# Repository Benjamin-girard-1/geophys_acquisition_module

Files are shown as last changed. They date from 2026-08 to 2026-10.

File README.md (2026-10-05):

# Geophysical Acquisition Module

Hardware, embedded firmware, protocol, and host-side software for a modular
geophysical data-acquisition system.

Version 2 uses an ESP32-S3 DevKit as its immutable compute platform and a custom
carrier PCB organized by hardware revision. The current hardware design includes
an AD7779 ADC, an LSM6DSV IMU, MAX-M10S GNSS, SD storage shared with a USB2641,
74HC/HCT595 GPIO expansion, and removable analog acquisition cards.

## Current status

The Version 2 firmware builds with ESP-IDF 5.5. Board safe-state and power
control, portable GPIO/SPI/UART, calibrated analog-input, and ROM-backed CRC
mechanisms, the 74HC/HCT595 driver, bounded analog-card ID measurement, and the
AD7779 register, lifecycle, channel/gain, fixed output-rate, signed sample
decoding, and conversion-frame validation foundations are implemented.
The acquisition task, SD recording owner, and recording controller now provide
the first end-to-end recording implementation and UART live-stream path, while
the remaining protocol inventory is still in progress. Hardware verification
is being completed incrementally.
The authoritative protocol defines fixed 64-byte command messages and portable
512-byte ADC data blocks shared by live capture and SD recording. Fixed command
framing, incremental stream recovery, CRC validation, and the
`HELLO`/`DEVICE_INFO` plus `DEVICE_GET_CONFIG`/`DEVICE_SET_CONFIG` UART slices
are implemented and verified on Rev-1 hardware. Live start/stop, complete
512-byte UART data delivery, the five SD-recording commands,
the portable `\DAT` encoder/decoder, fixed recording-buffer pool, and FatFs
writer are implemented; a clean Rev-1 build mounts and catalogs the SD card,
and now creates, syncs, closes, catalogs, and deletes ADC data files on Rev-1
hardware. A temporary test-only `0xf000` command can read closed recording
files in 38-byte UART chunks; it is implemented in the firmware and host codec
and was used to retrieve and CRC-validate a stored 512-byte block. A two-second
protocol probe produced and cleanly closed 404 fixed
512-byte records while configuration commands remained responsive. The probe
also exposed and led to correction of acquisition-task starvation and a
FreeRTOS queue-set accounting error that rebooted the device after several SD
records. Comparison with the working V1 driver identified and corrected
premature post-reset polling failure, missing reference-output power, missing
SPI software reset, and missing filter synchronization. The earlier all-zero
ADC response was a bench power issue: the main +5 V supply was absent, so 3V3A
was unavailable. Restoring +5 V allowed AD7779 initialization and recording to
proceed. The two expendable recordings that filled the card were enumerated
and deleted through the recording protocol, leaving an empty catalog. A
subsequent fresh probe recorded, downloaded, validated, and deleted ten
512-byte records. All record framing and CRCs passed. That early capture
contained 80 startup conversions near the AD7779 reset rate followed by a
sequence gap. The cause was an ESP-IDF side effect that enabled the DRDY pin
while its handler was attached, before ADC synchronization and SRC settling
completed. The platform attach operation now restores the pin to disabled and
the application enables it explicitly after `ad7779_start()`. A fresh 1 kSPS
probe then produced 25 status-OK records with no missing conversions. The
acquisition hot path now reserves SPI2 and its DMA resources once and launches
one hardware-CS-framed, prepared 32-byte transfer for each DRDY event. A
dedicated core-1 capture task advances the two-buffer DMA pipeline and
copies completed frames into a 256-frame ring; CRC validation, DAT construction,
and storage handoff run independently on core 0. SD recording now uses two
2 MiB PSRAM buffers: acquisition fills one continuously while the storage task
writes the other as one logical batch through a 32 KiB internal SDMMC staging
window. A 50-second four-channel 8 kSPS probe crossed both 2 MiB boundaries
without stopping acquisition or losing a conversion. The four-bit SDMMC bus
runs at its verified 40 MHz high-speed setting; every completed buffer and the
recording close are synchronized to the filesystem. The SD volume uses FAT32
with 32 KiB clusters so FatFs can issue 32 KiB multi-sector writes instead of
splitting at the former 4 KiB cluster boundaries. A two-second
channels-0–3 probe at 16 kSPS retained all 32,840 consecutive conversions at
625 x 100 ns spacing, with zero sequence gaps and an effective 16,000.04
conversions/s. DAT production waits for eight consecutive ADC frames to pass
CRC; the final short 16 kSPS probe and one-second 1 kSPS control contained only
status-OK records with zero missing conversions. A later 237-second capture retained
every conversion but exposed 72 isolated CRC-marked frame-phase errors at the
fixed 20 MHz SPI clock. Because AD7779 SDO output-valid timing does not support
that read rate in the worst case, lower clocks were tested. Fixed 8 MHz was
clean at 1 kSPS but could not complete valid frames at 16 kSPS with the current
DRDY-to-DMA launch latency. Fixed 10 MHz and 12 MHz produced records but still
lost conversions. A longer fixed-16-MHz capture then lost 23,438 conversions
and contained 243 CRC-marked frame errors in 93.9 seconds. The current
diagnostic build returned to fixed 20 MHz and lets the SPI peripheral assert
and release CS around every DMA burst. A two-second channels-0–3 16 kSPS probe
retained all 32,480 conversions with zero gaps, but two isolated phase errors
remained. Per-frame CS is therefore fast enough but does not by itself correct
the 20 MHz SDO integrity failure.
Configuration currently applies the stopped-device ADC rate, channel mask,
per-channel gains, and three sequenced acquisition rails; +5 VA and IMU remain
status-only. The +18 V rail is owned by a dedicated stopped-acquisition
magnetic SET/RESET command that returns the rail and pulse outputs to their
safe state. The Python host now has streaming
start/stop codecs, an incremental mixed command/data parser, named-reply
matching during live data, byte-exact validated capture, continuity counters,
and a desktop GUI with manual USB/COM selection, recording management, and a
separate live-plot tab. Its Config tab now reads device status and applies the
stopped-device ADC rate, four-channel slot selection, per-channel gains, and
acquisition-rail requests.
It also separates device-reported power-rail states from editable manual rail
requests and provides a detected-card-gated SET/RESET pulse control.
The GUI connection and recording catalog were exercised against Rev-1,
including creation, stop/close, catalog, and deletion of a GUI test recording.
A reversible channels-0–3 configuration update also passed on Rev-1. Firmware
live delivery was then exercised at 921600 baud with eight channels at 1 kSPS
and with four-channel decimation-by-5: start/stop replies and all received block
CRCs passed, streaming continued while an SD recording was opened, and
reconnect succeeded after the five-second session timeout. The live blocks
still expose the known ADC critical status and startup sequence loss, so
scientific-data validation remains open.

On 2026-09-29, the currently inserted SD card mounted and its six-file catalog
remained readable, but a new recording faulted on its first 512-byte write.
The failure reproduced with the untouched default `0xFF` configuration and
with channels 0–3 (`0x0F`), including after a device reset, while an `0x0F`
live stream continued to deliver validly framed blocks. Querying the retained
recording failure through `RECORDING_STOP` returned `0x0a` (`storage full`).
This isolates the failure from host configuration and four-channel
acquisition; space must be freed or the FAT32 volume repaired before recording.

The first Bluetooth Low Energy slice is also implemented. When enabled, the
ESP32-S3 advertises `Geophys Acquisition`, accepts one BLE central, and answers
`HELLO` with the existing `DEVICE_INFO` message. The desktop host can scan,
connect, and display that identity; other commands and live data remain
disabled on Bluetooth for now. Rev-1 bench verification passed BLE discovery
and `HELLO` while a USB command session remained active. The current
2026-10-03 field-test build intentionally sets `APP_BLUETOOTH_ENABLED` to zero
in `version_2/firmware/app/app.c`. This radio-silent diagnostic configuration
removed the measured 60–70 ms BLE advertising disturbance and preserves the
implemented BLE code for later re-enablement.

The same field-test build enables unattended SD recording. Its defaults are
8 kSPS, channels 0–3 enabled, gain x8 on channels 0–2, and gain x1 on channel
3; channels 4–7 are disabled. It waits five seconds after application
initialization, then creates the first free name from `field000` through
`field254` and starts acquisition. Holding the ESP32-S3 DevKitC BOOT button for
three seconds stops the ADC, drains the PSRAM buffers, syncs the file, and
closes it. A hard power-off cannot run that cleanup: after holding BOOT, wait
for the close to finish before switching the battery off. The RESET button
remains an immediate reset and must not be used to stop a recording.

The complete wire contract is
[shared/protocol/protocol.md](shared/protocol/protocol.md). It is the sole
authority for framing, identifiers, results, command payloads, and ADC data
blocks.

See [ARCHITECTURE.md](ARCHITECTURE.md) for module responsibilities, dependency
rules, initialization order, and the detailed implementation-status table.
Milestone-1 execution and verification are tracked in
[version_2/docs/firmware_implementation_checklist.md](version_2/docs/firmware_implementation_checklist.md).

## Repository layout

```text
.
├── ARCHITECTURE.md              Firmware architecture and dependency rules
├── shared/
│   ├── kicad-libraries/         Shared KiCad symbols and footprints
│   ├── protocol/                Firmware/host wire-protocol specification
│   ├── third_party/             Pinned external dependencies
│   └── tools/                   Repository-wide development utilities
├── version_1/                   Earlier product generation
└── version_2/
    ├── docs/                    Datasheet links and supporting documentation
    ├── firmware/
    │   ├── common/              Portable types shared across firmware layers
    │   ├── main/                ESP-IDF entry point and composition root
    │   ├── app/                 Product behavior and FreeRTOS tasks
    │   ├── boards/              Custom carrier-board integration by revision
    │   ├── analog_cards/        Removable analog-card integration
    │   ├── drivers/             Portable component-specific drivers
    │   ├── data_format/         Portable serialized acquisition records
    │   ├── protocol/            Firmware framing and message encoding
    │   ├── transports/          UART, USB, and future byte transports
    │   ├── platform/
    │   │   └── esp32s3_devkit/  Immutable DevKit and ESP-IDF integration
    │   └── cmake/               Shared build helpers when required
    ├── hardware/
    │   ├── pcb/                 KiCad projects organized by revision
    │   └── mechanical/          Mechanical design files
    └── software/
        ├── apps/
        │   ├── host/            Device control and live monitoring
        │   └── dev_tools/       Developer-only recording diagnostics
        └── packages/
            └── data/            Shared Python data-format decoder
```

## Firmware boundaries

- `common/` defines dependency-free status categories and other truly
  cross-layer portable types.
- `main/` initializes the platform, selected board, and application.
- `app/` owns acquisition, processing, storage, communication, and product state.
- `boards/` maps the custom PCB wiring to portable drivers and platform services, including the
  Rev-1 mainboard's 18 V rail and physical shift-register outputs.
- `analog_cards/` describes complete removable card assemblies. Magnetic SET/RESET pulse generation
  belongs in `analog_cards/magnetic/` and is not shared with `analog_cards/acc_geoph/`.
- `drivers/` implements individual components without depending on ESP-IDF,
  FreeRTOS, or board wiring.
- `data_format/` defines transport- and storage-independent acquisition-record
  serialization.
- `platform/esp32s3_devkit/` isolates ESP-IDF and immutable DevKit details.
- `protocol/` implements transport-independent framing and messages.
- `transports/` move bytes without interpreting application commands.
- `shared/protocol/` defines the wire contract used by firmware and host tools.

## Version 2 firmware components

The current scaffolds cover:

- AD7779 eight-channel ADC
- LSM6DSV accelerometer and gyroscope
- MAX-M10S GNSS receiver
- 74HC/HCT595 shift register
- Magnetic analog acquisition card
- Geophysical accelerometer card
- Analog-card detection
- Acquisition, processing, storage, communication, and Bluetooth tasks
- UART and USB transports
- Transport-independent protocol framing and messages
- Portable 512-byte ADC-record format

## Building

Activate an ESP-IDF 5.5 environment, then build from `version_2/firmware/`:

```sh
cd version_2/firmware
idf.py build
idf.py flash monitor
```

Run `idf.py set-target esp32s3` first only when creating a fresh local build
configuration or changing targets.

An existing local `sdkconfig` created before BLE support will not automatically
pick up the new Bluetooth defaults. Back it up once and regenerate it before
the first BLE-enabled build:

```sh
mv sdkconfig sdkconfig.pre-ble
idf.py set-target esp32s3
```

Generated `build/`, `sdkconfig`, managed components, binaries, KiCad local state,
editor files, and locally stored vendor datasheet PDFs are excluded by the root
`.gitignore`. Datasheet source links remain tracked in
`version_2/docs/datasheet.txt`.

## Development guidance

Before adding a module or function, consult the “Where new code belongs” table
in [ARCHITECTURE.md](ARCHITECTURE.md#where-new-code-belongs). Keep component
drivers portable, keep physical Rev-1 wiring in `boards/rev_1`, and keep protocol
encoding independent of UART, USB, or Bluetooth.

Update the architecture implementation-status table when an interface becomes
usable, an implementation passes its software tests, or functionality is
verified on hardware.

## Plotting an extracted recording

The small developer tool opens a file chooser in the sibling
`geophys_acquisition_data/` directory, then validates and plots the selected
recording:

```sh
.venv/bin/python version_2/software/apps/dev_tools/launch_plot.py
```

Pass a path as the first argument to plot a different recording. The application
reads the binary file without modifying it and displays raw ADC counts.

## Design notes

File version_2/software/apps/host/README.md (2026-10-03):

# Version 2 Host Application

## Status

This directory contains the independent Python reference host for the shared wire
protocol. It now includes the command and ADC-record codecs, a corruption-
tolerant mixed `\CMD`/`\DAT` parser, exact named-reply matching while ADC data
is in flight, raw validated-block capture, live continuity/error counters, and
a Tk desktop application with manual USB/COM selection. The desktop app has a
recording catalog, embedded overlay plots, and a functional configuration tab.
The live view uses at most two graphs, routes each channel to either graph or
hides it, and applies user-set per-channel display subtraction constants without
changing captured raw data. CH3 and CH7 are hidden by default. Graph visibility
follows the configured acquisition slots, so the second graph is not created
until slot 2 is enabled. The configuration tab can change ADC sample rate,
select slot 1 (channels
0–3), slot 2 (channels 4–7), or both, set each channel's gain, display the five
device-reported power-rail states, and include manually requested rail states
in `DEVICE_SET_CONFIG`. Serial work runs on a background thread so the window
remains responsive.

The connection selector also supports the first Bluetooth Low Energy slice.
It scans for `Geophys Acquisition`, connects, sends `HELLO`, and displays the
returned device identity. Recording controls and live streaming remain
disabled for BLE connections until those commands are implemented on that
transport.

The firmware and host now support live start/stop and asynchronous `\DAT`
delivery over the USB/UART link. Rev-1 hardware returned CRC-valid eight-channel
blocks at 1 kSPS and four-channel blocks with decimation by 5. Streaming was
also exercised while SD recording was active, and reconnect succeeded after
the firmware's five-second session timeout. The received blocks still expose
the known ADC critical status and startup sequence loss, so scientific-data
validation remains open.

## Setup

From the repository root:

```sh
python3 -m venv .venv
source .venv/bin/activate
python3 -m pip install -e version_2/software/packages/data \
  -e version_2/software/apps/host
```

Launch the desktop application from the repository root:

```sh
python3 version_2/software/apps/host/launch_host.py
```

Select the device's USB/COM port, leave the baud rate at `921600`, and click
**Connect**. The recordings catalog and current device configuration load
automatically. In the **Config** tab, select **Acquire this slot** for slot 1
to use only channels 0–3, choose any required sample rate and gains, and click
**Apply changes**. Configuration changes are available while recording and
live streaming are stopped. Power rails have separate **Reported** and
**Manual request** columns; the reported state from the device is always
authoritative. The +3.3 VA, +10 V / 9 VA, and -5 VA requests are applied by the
firmware in the Rev-1 power sequence. +5 VA is status-only because Rev-1 has no
software enable. +18 V is pulse-controlled: select a detected magnetic-card
slot and SET or RESET, then click **Send pulse**. The button is available only
while acquisition is stopped and no configuration edits are pending. IMU
fields remain status-only.
ADC settings are runtime state and return to firmware defaults after a device
reboot. Use the **Live Stream** tab to select channels and decimation, then
click **Start live streaming**.

The shared protocol and GUI require both live streaming and recording to be
stopped before applying configuration changes or sending a magnetic pulse.
Recording controls also require the device to report an SD card in the ready
state. If an active recording stops asynchronously, the GUI now reports the
stop explicitly, queries the retained failure through `RECORDING_STOP`, and
identifies conditions such as `storage full` instead of leaving a stale
recording status visible.

For Bluetooth, select **Bluetooth LE**, click **Refresh**, select the advertised
device, and click **Connect**. USB may remain plugged in for power or debugging;
BLE advertising and the `HELLO` exchange remain available at the same time.

The same application can also be launched as a module:

```sh
python3 -m geophys_host
```

The command-line connection probe remains available:

```sh
python3 -m geophys_host.cli hello /dev/cu.usbserial-PORT
```

Scan for BLE devices and perform the same identity request with:

```sh
python3 -m geophys_host.cli ble-scan
python3 -m geophys_host.cli ble-hello DEVICE-IDENTIFIER
```

The earlier command-line live view also remains available:

```sh
python3 -m geophys_host.cli live /dev/cu.usbserial-PORT
```

Capture every validated 512-byte block byte-for-byte while plotting:

```sh
python3 -m geophys_host.cli live /dev/cu.usbserial-PORT \
  --channels all --decimation 2 --capture capture.dat
```

Use `--terminal` instead of opening its separate graph, or `--duration 30` for
a bounded run. The desktop app sends the required once-per-second
`DEVICE_GET_CONFIG` keepalive for the entire connection. Catalog refreshes run
in the serial worker and disable only catalog-specific controls.

The live display currently labels inputs `CH0` through `CH7` and shows raw
signed 24-bit ADC counts. Physical card-axis/thermistor names and calibrated
units will be added only after their channel mapping and calibration are
defined and verified.

Run the portable tests with:

```sh
python3 -m unittest discover -s version_2/software/apps/host/tests -v
```

## Modules

```text
geophys_host/
├── protocol.py       Fixed 64-byte command codecs
├── adc_record.py     Compatibility imports for the shared data decoder
├── stream_parser.py  Incremental mixed `\CMD`/`\DAT` recovery
├── serial_client.py  Serial connection and named-reply matching
├── ble_client.py     BLE discovery, connection, and HELLO exchange
├── capture.py        Raw validated-record capture
├── live.py           Stream counters, rolling data model, and plot
├── gui.py            Desktop connection, recordings, and live-stream tabs
└── cli.py            Command-line device and live-stream interface

tests/
└── shared vectors, stream fragmentation, and named-reply tests
```

The Python decoder lives in `software/packages/data/geophys_data/` and remains
independent from the C encoder. Both sides consume the byte-exact vectors under
`shared/protocol/test_vectors/`.

## Dependency boundary

- The shared `geophys_data` package and `stream_parser.py` do not open serial
  ports or update a UI.
- The GUI sends device operations to one background serial owner and updates
  Tk widgets only from the GUI thread.
- Connection adapters move bytes and handle transport-specific fragmentation
  without redefining commands or interpreting scientific samples. The client
  permits one outstanding command and waits for its defined reply ID.
- UART and Bluetooth clients use the same command codec. The current BLE client
  intentionally exposes only `HELLO`; recording and sample streaming remain
  USB/UART-only.
- `capture.py` persists only complete, validated records. Session metadata and
  scientific exports remain future work.
- Plotting consumes decoded data and never changes the raw capture bytes.

See `version_2/docs/uart_host_integration_plan.md` for the proposed sequence and
review gates.

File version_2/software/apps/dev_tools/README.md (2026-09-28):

# Geophys Developer Tools

These developer-only diagnostics validate a raw SD recording, print a short
continuity summary, and open an interactive waveform and FFT viewer. They are
separate from the future production MTH5 builder.

Set up the local environment from the repository root:

```sh
python3 -m venv .venv
source .venv/bin/activate
python3 -m pip install -e version_2/software/packages/data \
  -e version_2/software/apps/dev_tools
```

From the repository root, launch the tool:

```sh
.venv/bin/python version_2/software/apps/dev_tools/launch_plot.py
```

A native file chooser opens in the sibling `geophys_acquisition_data/`
directory. On macOS it uses Cocoa directly instead of Tk so directory
navigation is reliable. Canceling it exits without opening a plot.

Pass a recording path to plot a different file:

```sh
.venv/bin/python version_2/software/apps/dev_tools/launch_plot.py /path/to/recording
```

Channels 0 through 3 are plotted by default:

```sh
.venv/bin/python version_2/software/apps/dev_tools/launch_plot.py \
  /path/to/recording
```

The `--channels` choices are `all`, `0-3`, and `4-7`. This option chooses the
initial selection for both plots. Use `--channels all` to initially show every
recorded channel. When the recording path is omitted, the native file chooser
opens and channels 0–3 are initially selected.

The viewer has separate channel checkbox groups for the waveform and FFT, so
each plot can display a different channel combination. The **All** and **None**
buttons below either group provide quick selection. FFTs use a Hann window and
display single-sided amplitude. The FFT defaults to a logarithmic dBFS scale,
omits the exact 0 Hz bin, and can be switched back to linear ADC counts with
the **FFT scale** control. The editable **Trim start (s)** and **Trim end (s)**
fields control how much data is excluded from both plots and the FFT. Press
Enter in either field to apply the values. They default to 1 second at the
start and 0 seconds at the end.

The recording is read but never modified. The plot displays raw signed 24-bit
ADC counts because physical channel names and calibration are not defined yet.

The waveform is reduced to at most 100,000 displayed points for interactive
performance. FFT calculations always use every sample in the selected time
range; display reduction is never applied to spectral analysis.

## Convert a binary recording to CSV

Convert a validated recording from the portable 512-byte block format:

```sh
.venv/bin/python version_2/software/apps/dev_tools/launch_convert.py \
  ../geophys_acquisition_data/scratch/V2_noise_test
```

By default, the CSV is written to the external
`geophys_acquisition_data/scratch/` directory and is therefore kept outside
the source repository. Existing files are not overwritten. Use `--force` to
replace one, or `--output PATH` to choose another destination:

```sh
.venv/bin/python version_2/software/apps/dev_tools/launch_convert.py \
  /path/to/recording --output /path/to/output.csv
```

The CSV has one row per simultaneous ADC conversion. It preserves the relative
and raw monotonic timestamps, conversion sequence, record and payload numbers,
record status, channel mask, packed gain, sample period, and signed raw counts
for channels 0 through 7. Unrecorded channels are left empty. Counts are not
converted to volts because no physical calibration is defined yet.

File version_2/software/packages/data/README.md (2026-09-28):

# Geophys Data

This flat-layout Python package contains the data-format code shared by the
host and developer diagnostics. It has no device-transport, GUI, or Matplotlib
dependency.

The authoritative byte layout remains `shared/protocol/protocol.md`.

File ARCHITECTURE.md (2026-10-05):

# Geophysical Acquisition Module Firmware Architecture

## Purpose

This document defines where firmware responsibilities belong, how modules may
depend on each other, and where new code should be added. Its purpose is to keep
the repository predictable as the product grows and to prevent hardware wiring,
component logic, protocol logic, and application behavior from becoming mixed.

The document describes the intended architecture. A directory or file may exist
before its interface or implementation is complete; see the implementation
status table at the end of this document.

## Design principles

- Component drivers remain independent of ESP-IDF, board wiring, FreeRTOS,
  storage, and communication transports.
- The ESP32-S3 DevKit is an immutable compute platform. Custom PCB behavior and
  wiring belong to the selected board revision.
- Product behavior belongs to the application layer, not to component drivers or
  platform adapters.
- UART, USB, Bluetooth, and future links carry the same transport-independent
  protocol.
- Stateful hardware resources have one owner during normal operation.
- Interrupt handlers do the minimum work necessary and wake the owning task.
- Hardware starts in a safe state and startup stops safely when a required
  subsystem cannot be initialized.
- External dependencies are pinned and are not modified locally.
- Generated files and local tool state are not committed.

## Repository layout

```text
ARCHITECTURE.md                  This architecture and dependency contract
README.md                        Project overview and getting-started information

shared/
├── kicad-libraries/             Shared schematic and footprint libraries
├── protocol/                    Cross-platform wire-protocol specification
│   ├── protocol.md              Complete authoritative wire contract
│   └── test_vectors/            Valid and invalid protocol examples
├── third_party/                 Pinned external dependencies
└── tools/                       Repository-wide development utilities

version_1/                       Earlier hardware/firmware generation

version_2/
├── docs/                        Datasheet references and product documentation
├── hardware/
│   ├── pcb/                     KiCad projects organized by board revision
│   └── mechanical/              Mechanical design files
├── firmware/
│   ├── common/                  Portable types shared across firmware layers
│   ├── main/                    ESP-IDF main component and composition root
│   │   └── main.c
│   ├── app/                     Product behavior and FreeRTOS task ownership
│   ├── boards/                  Custom, modifiable PCB integration
│   │   ├── rev_1/
│   │   └── rev_2/
│   ├── analog_cards/            Pluggable analog-card integration
│   │   ├── magnetic/
│   │   └── acc_geoph/
│   ├── drivers/                 Portable component-specific drivers
│   │   ├── adc/                 AD7779
│   │   ├── gnss/                MAX-M10S
│   │   ├── imu/                 LSM6DSV
│   │   └── gpio_expansion/      74HC/HCT595 shift register
│   ├── data_format/             Portable acquisition-record serialization
│   ├── protocol/                Firmware protocol encoder and decoder
│   ├── transports/              UART, USB, and future byte transports
│   ├── platform/
│   │   └── esp32s3_devkit/      Immutable DevKit and ESP-IDF integration
│   │       ├── include/
│   │       ├── src/
│   │       ├── linker/          Only if ESP-IDF defaults must be customized
│   │       └── startup/         Only if ESP-IDF startup must be customized
│   └── cmake/                   Shared build helpers, when required
└── software/
    ├── apps/
    │   ├── host/                Device control and live monitoring
    │   └── dev_tools/           Developer-only recording diagnostics
    └── packages/
        └── data/                Shared Python ADC-record decoder
```

`version_2/firmware/build/` is generated by ESP-IDF and is not part of the
source architecture.

## Where new code belongs

| New code | Location |
|---|---|
| Portable status categories or other truly cross-layer firmware types | `firmware/common/` |
| Product mode, recording behavior, or acquisition policy | `firmware/app/` |
| FreeRTOS task and its owned queues or buffers | `firmware/app/` |
| Rev-1 GPIO, chip select, polarity, or peripheral assignment | `firmware/boards/rev_1/` |
| Behavior specific to a removable analog card | `firmware/analog_cards/<card>/` |
| Magnetic-card SET/RESET pulse sequence, width, dead time, and settling policy | `firmware/analog_cards/magnetic/` |
| Rev-1 18 V rail control and physical SET/RESET shift-register mapping | `firmware/boards/rev_1/` |
| Register map or datasheet behavior for one IC | `firmware/drivers/<component>/` |
| Packed ADC records shared by transports and future storage | `firmware/data_format/` |
| ESP-IDF SPI, I2C, UART, GPIO, timer, or SDMMC adapter | `firmware/platform/esp32s3_devkit/` |
| Message framing or serialization | `firmware/protocol/` |
| USB, UART, or Bluetooth byte movement | `firmware/transports/` |
| Wire-format contract shared with the host | `shared/protocol/` |
| Device control and live host behavior | `version_2/software/apps/host/` |
| Developer plots, FFTs, and recording diagnostics | `version_2/software/apps/dev_tools/` |
| Python data-format code shared by host-side apps | `version_2/software/packages/data/` |
| PCB or electrical design | `version_2/hardware/` |

When a change seems to fit in more than one location, place the hardware-neutral
policy at the higher layer and the hardware-specific mechanism at the lower
layer. For example, the application decides when recording starts, the storage
task owns the filesystem, the board keeps the Rev-1 SD mux in its fixed ESP32
state, and the platform performs the SDMMC operations. Likewise, the magnetic
card module defines how a magnetic SET/RESET pulse is generated, while the
Rev-1 board implements the mainboard's 18 V rail control and physical SH2 output
mapping used by that sequence.

## Dependency direction

```text
app_main
├── platform
├── board
└── application
    ├── acquisition / processing / storage
    ├── data-format encoder
    └── communication task
        ├── protocol
        └── transport interface
            ├── UART transport
            ├── USB transport
            └── Bluetooth transport

board
├── analog-card integrations
├── component drivers
└── platform services

analog-card integrations
└── component drivers

data-format encoder
└── portable C types and algorithms only

transports
└── platform services

platform
└── ESP-IDF / FreeRTOS
```

Allowed dependencies:

- All firmware layers may use the portable types in `common/`; `common/` does
  not depend on any other firmware component, ESP-IDF, or FreeRTOS.
- `main/` initializes the platform, selected board revision, and application.
- `app/` uses application types, board-level services, protocol interfaces, and
  transport-independent communication interfaces.
- `boards/` uses analog-card modules, component drivers, and platform services.
- `analog_cards/` uses portable component interfaces and describes card-level
  topology or sequencing without knowing ESP32 GPIO numbers.
- `data_format/` uses portable C types and algorithms only. It knows neither
  UART framing nor FatFs/SD write policy.
- `protocol/` uses portable C types and algorithms only.
- `transports/` use their corresponding platform or third-party service and do
  not interpret application messages.
- `drivers/` use portable callbacks and opaque contexts supplied during
  initialization. The AD7779 driver directly uses only the stateless
  `platform_crc8_be()` platform primitive; its source still contains no
  ESP-IDF types or headers.
- `platform/esp32s3_devkit/` uses ESP-IDF and FreeRTOS APIs.

Forbidden dependencies:

- Component drivers must not include ESP-IDF, board, application, protocol, or
  FreeRTOS headers.
- Platform code must not know that an AD7779, LSM6DSV, MAX-M10S, analog card, or
  other product component uses a peripheral.
- Analog-card modules must not contain ESP32 GPIO numbers or call ESP-IDF APIs.
- Protocol framing and message encoding must not call UART, USB, or Bluetooth
  implementations directly.
- Transports must not decode product commands or manipulate sensors.
- Application tasks must not manipulate component registers or ESP32 GPIO
  registers directly.
- Third-party source code must not be edited to add product behavior.

## Firmware entry point

`version_2/firmware/main/main.c` is the composition root. It provides ESP-IDF's
`app_main()` and is limited to:

1. Initialize required platform services.
2. Initialize the selected custom board revision.
3. Place the board in its defined safe initial state.
4. Initialize application resources.
5. Create application tasks, queues, and synchronization objects.
6. Enter a safe and diagnosable failure state if startup cannot complete.

ESP-IDF starts the FreeRTOS scheduler before it calls `app_main()`. The firmware
must not call `vTaskStartScheduler()`. `app_main()` may return after creating the
long-lived application tasks.

Product algorithms, peripheral register configuration, packet parsing, and
long-running acquisition loops do not belong in `main.c`.

## Application layer

The application layer decides what the acquisition module does. It works with
timestamped samples, recordings, configuration, commands, product state, and
diagnostics through board-level and protocol-level interfaces.

### `app.c` and `app.h`

These files coordinate application startup. They create application-owned
queues, buffers, synchronization objects, and tasks. They do not accumulate all
product behavior into one large loop.

### Application types

Types exchanged between application modules should eventually be collected in
`app_types.h` or smaller domain headers. Examples include:

- Timestamped ADC and IMU samples.
- GNSS time and position fixes.
- Recording and acquisition requests.
- Application modes and subsystem health.
- Configuration values expressed in physical units.

Application types must not contain:

- ESP-IDF handles or register definitions.
- Board GPIO or peripheral assignments.
- Component register values.
- Raw on-wire protocol structures.
- FreeRTOS internal implementation structures.

## FreeRTOS task ownership

One task owns each stateful resource during normal operation. Other tasks
communicate with the owner through queues, task notifications, stream buffers,
or explicit request interfaces.

| Task | Intended responsibility | Current status |
|---|---|---|
| `task_acquisition` | Configure acquisition devices, wait for data-ready events, read samples or FIFOs, and timestamp data | SD-recording and bounded UART live-record paths hardware exercised; DRDY-rate/sample-validity verification open |
| `task_processing` | Calibration, filtering, derived channels, and event processing when workload justifies a separate task | Provisional scaffold |
| `task_storage` | Own filesystem operations, recordings, buffered writes, flushes, and storage faults | Implemented for SD recording; fault-injection tests open |
| `task_communication` | Decode protocol messages, dispatch commands, encode responses, and send complete live records | Discovery, configuration, streaming, and recording commands implemented |
| `task_bluetooth` | Manage Bluetooth connection state and asynchronous radio events without duplicating protocol behavior | BLE advertising, connection, and `HELLO`/`DEVICE_INFO` implemented; other commands remain disabled |
| `task_field_recording` | Start a uniquely named unattended recording after boot and convert a long BOOT-button hold into the normal synchronized recording stop | Enabled in the radio-silent field build; hardware verification pending |

`task_processing` should remain an ordinary application module unless its CPU
time, latency, or buffering requirements justify an independent task.

`task_bluetooth` should remain separate only if the Bluetooth stack or connection
management requires an asynchronous state machine. UART, USB, and Bluetooth
must not each implement their own command protocol.

Interrupt handlers acknowledge the event, capture essential state when needed,
and notify the owning task. They do not parse messages, perform long bus
transactions, write files, or run product algorithms.

## Custom board integration

### `board_config.h`

`boards/rev_1/board_config.h` is the authoritative firmware mapping for the
modifiable Rev-1 carrier PCB. It contains:

- ESP32 GPIO assignments and signal polarities.
- SPI, I2C, UART, and SDMMC controller selection.
- Chip-select, reset, enable, interrupt, and data-ready assignments.
- Power-rail and source-presence controls.
- SD/USB multiplexer control signals.
- Analog-card detect and control assignments.
- Bus limits, timing limits, and board-level timeouts.

It must not contain product algorithms, component register tables, protocol
definitions, or long executable procedures.

### `board.c` and `board.h`

`board.c` initializes the custom PCB and connects portable drivers to platform
services. For example, it associates an AD7779 instance with the selected SPI
service, chip-select signal, reset signal, data-ready interrupt, and timing
callbacks.

`board.h` exposes board-level services to the application without leaking
ESP-IDF handles, GPIO numbers, or component register details. If `board.c`
becomes too large, it may be divided by resource while `board.h` remains the
public application-facing interface.

Safe output levels must be established before a peripheral or task can use the
board. Power enables, sensor set/reset controls, the shift-register output
enable, ADC control signals, and the SD/USB multiplexer require explicit startup
states derived from the schematic and component datasheets.

## ESP32-S3 DevKit platform

`platform/esp32s3_devkit/` represents the immutable ESP32-S3 DevKit compute
platform and its ESP-IDF integration. The name intentionally distinguishes the
fixed DevKit from the custom, modifiable carrier PCB in `boards/rev_1/`.

The platform layer is responsible for mechanisms such as:

- ESP-IDF system, clock, and power initialization that the application must
  explicitly control.
- GPIO, SPI, I2C, UART, SDMMC, USB, DMA, timer, and interrupt operations.
- ROM-backed CRC primitives behind firmware-owned, ESP-IDF-free interfaces.
- Monotonic time, delays, and critical sections.
- ESP-IDF and FreeRTOS error translation.
- DevKit-intrinsic resources and immutable constraints.
- Build integration and optional custom partition, linker, or startup support.

Platform interfaces describe MCU and DevKit services. They do not describe
which product sensor uses those services. Carrier-board GPIO mappings and
product component instances remain in `boards/rev_1/`.

ESP-IDF normally supplies startup code, the linker layout, and the FreeRTOS port.
The local `startup/` and `linker/` directories should remain empty unless a
documented product requirement needs to override an ESP-IDF default.

## Analog-card integration

`analog_cards/` describes removable or selectable card assemblies rather than a
single integrated circuit. An analog-card module may know:

- Which portable component drivers make up that card.
- Card-level channel ordering and supported measurements.
- Required set/reset or excitation sequences.
- Card-level timing and settling requirements.
- Detection and identification rules.
- Card-specific health and availability states.

An analog-card module must not know ESP32 GPIO numbers, ESP-IDF peripheral
handles, protocol packet layouts, filesystem behavior, or user-interface policy.
The selected `board` supplies its control and bus callbacks.

`analog_cards/magnetic/` owns the complete magnetic SET/RESET behavior: allowed
operations, pulse width, ordering, dead time, and post-pulse settling policy. It
uses callbacks supplied at initialization and never knows the 18 V enable bit or
the SET/RESET shift-register positions. The Rev-1 board owns those mainboard
mechanisms and remains the only writer of the physical 74HC595 chain.

`analog_cards/acc_geoph/` has no SET/RESET pulse behavior. Card-specific gain
control for that card belongs in its own module and is independent of the
magnetic pulse interface.

Current card scaffolds are:

- `analog_cards/magnetic/` for the magnetic acquisition card.
- `analog_cards/acc_geoph/` for the geophysical accelerometer card.
- `analog_cards/card_detect.*` for common card-presence handling.

## Component drivers

Each driver describes one physical component according to its datasheet.

Typical files are:

```text
component.c          Public behavior and datasheet logic
component.h          Public portable interface
component_reg.h      Private register and bit definitions, when applicable
```

Current component drivers are:

- `ad7779`: eight-channel ADC control, status, and sample-frame handling.
- `lsm6dsv`: accelerometer and gyroscope configuration and sample handling.
- `max_m10s`: GNSS configuration and message handling.
- `74hc_hct595`: serial-to-parallel output control.

A component driver may know:

- Supported modes, ranges, data rates, and frequencies.
- Register addresses, commands, and bit fields.
- Component-specific SPI, I2C, or UART transaction formats.
- FIFO and raw sample layout.
- Conversion from raw values to documented units.
- Component identity and component-level error conditions.

A component driver must not know:

- Which ESP32 peripheral or GPIO is used.
- How ESP-IDF performs a transfer.
- Which custom board revision is active.
- Which FreeRTOS task called it.
- Whether data will be stored, processed, or transmitted.

The board supplies portable communication, GPIO, delay, and time callbacks plus
an opaque context to each driver instance. Unsupported functionality is omitted
or returns an explicit not-supported result; it is not declared without an
implementation.

## Storage and fixed SD-card ownership

The storage architecture crosses several layers:

- `task_storage` owns normal filesystem access and recording files.
- `board` initializes the product-specific SD/USB multiplexer once for ESP32
  ownership and holds the USB2641 reset/isolated.
- `platform` performs ESP-IDF SDMMC and filesystem operations.

The storage implementation models these states:

- Unavailable or uninitialized.
- Owned by the ESP32 for recording or playback.
- Faulted or unexpectedly removed.

V2 Rev-1 firmware does not expose the SD card through the USB2641 and does not
switch SD ownership at runtime. The exact fixed mux select/enable levels and
USB2641 reset state belong to the Rev-1 board implementation and must be
verified against the schematic and datasheets.

### Portable ADC records

`firmware/data_format/` owns the portable 512-byte ADC record shared by UART
capture, future Bluetooth capture, and SD recording. It explicitly serializes
record metadata and packed signed 24-bit
samples without depending on the AD7779 driver, application queues, UART,
Bluetooth, ESP-IDF, FatFs, or SD hardware.

The 512-byte logical record size is independent of the acquisition task's RAM
block size and the storage task's eventual multi-record filesystem write size.
The byte contract is defined by `shared/protocol/protocol.md`.

## Communication architecture

UART, USB, Bluetooth, and future transports carry one application protocol.
Every enabled command transport exposes the same command meanings. Feature
availability is reported explicitly and does not depend on whether a request
arrived through UART or Bluetooth. A constrained link may negotiate a reduced
live stream profile without changing the scientific ADC acquisition settings or
silently dropping data.

```text
Host application
├── USB connection ──────────┐
├── UART connection ─────────┤
└── Bluetooth connection ────┤
                             v
                    Firmware protocol
                             v
                    Application commands
```

### Protocol

`firmware/protocol/` is independent of physical transports:

- `protocol_frame` detects frame boundaries and checks framing integrity.
- `protocol_messages` serializes and deserializes typed command and data
  payloads.
- Protocol state allows one outstanding host command, matches its named reply,
  and does not treat asynchronous `\DAT` blocks as command responses.

Parsing accepts partial input and multiple frames in one buffer. It must not
depend on USB packet boundaries, UART read sizes, or Bluetooth packet sizes.

Raw C structures are never transmitted directly. Fields are serialized
explicitly using fixed widths and a specified byte order.

### Transports

`transports/transport.h` defines the common byte-transport contract. UART, USB,
and Bluetooth implementations independently manage connection state,
partial transfers, buffering, and backpressure. They do not interpret product
commands.

Debug text must never be inserted into the binary protocol stream. Logging uses
a dedicated debug channel or an explicitly separate framing/channel mechanism.

### Shared specification

`shared/protocol/` is the contract between firmware and the host application. It
contains or will contain:

- Common protocol invariants and transport-parity rules.
- Protocol version and compatibility rules.
- Frame and message layouts.
- Detailed command, response, and state-transition semantics.
- Message identifiers and stable status codes.
- Byte order and checksum/CRC definitions.
- Units, scaling, and invalid-value representations.
- Valid and invalid test vectors.
- Recording transfer, interruption, and resume behavior.

The firmware and host application implement this specification independently
and are tested against the same vectors.

## Time and data conventions

- Application-facing measurements use documented physical units.
- Units appear in field names or API documentation.
- Fixed-width integer types are used where binary representation matters.
- Protocol and stored-data layouts are serialized explicitly.
- Monotonic acquisition time and GNSS/UTC time are separate clock domains.
- Every timestamp type identifies its unit, epoch, and clock domain.
- Mapping GNSS time to acquisition time is explicit and includes validity and
  uncertainty when available.
- Driver-specific types do not leak into processing, storage, or protocol layers
  unless that dependency is intentional and documented.
- Mutable global state is avoided. Shared state has one owner and explicit
  synchronization.
- Dynamic allocation after application startup is avoided unless a bounded and
  reviewed use case requires it.

## Error handling

Each layer translates errors at its boundary:

- Platform errors describe ESP-IDF, peripheral, timing, or MCU failures.
- Driver errors describe component failures or invalid component parameters.
- Analog-card errors describe card detection, identification, sequencing, or
  availability failures.
- Board errors identify unavailable or incorrectly initialized resources.
- Application errors describe product operations such as acquisition or
  recording failures.
- Protocol responses expose stable host-visible status codes.

ESP-IDF error values, low-level bus errors, and private driver status values must
not be transmitted directly as the public protocol.

Fatal startup failures place the hardware in a safe and diagnosable state rather
than continuing with partially initialized resources.

## Initialization order

The intended ESP-IDF startup sequence is:

```text
ESP32-S3 reset
    v
ESP-IDF bootloader and system initialization
    v
FreeRTOS scheduler and ESP-IDF main task
    v
app_main
    v
required platform services
    v
selected board revision and safe outputs
    v
component and analog-card instances
    v
application queues, buffers, and tasks
    v
optional unattended-recording startup delay
    v
normal operation
```

Tasks must not access a resource until its platform, board, and driver
initialization has completed successfully. Optional devices may be marked
unavailable when the current application contract permits degraded operation;
required-device failures prevent acquisition from starting.

## Build and dependency conventions

- `version_2/firmware/CMakeLists.txt` is the ESP-IDF project entry point.
- `version_2/firmware/main/` is the ESP-IDF main component.
- Other architectural directories are registered as ESP-IDF components or
  component search paths without changing their ownership boundaries.
- Reproducible defaults belong in `sdkconfig.defaults`; developer-generated
  `sdkconfig` files remain local unless a deliberate decision says otherwise.
- ESP-IDF Component Manager dependencies use `idf_component.yml` and a committed
  dependency lockfile when applicable.
- `build/`, `managed_components/`, generated binaries, and IDE state are ignored.
- Vendor datasheet PDFs in `version_2/docs/datasheets/` remain local; their
  source links are tracked instead.
- Warnings should be enabled broadly and treated as errors in automated builds
  once the initial platform scaffold is stable.

## Verification strategy

- Portable drivers are unit-tested on the host with fake bus, GPIO, delay, and
  time callbacks.
- Protocol encoding and parsing are tested against shared golden vectors,
  malformed data, partial frames, and multiple frames per input buffer.
- Board and platform services receive hardware smoke tests for each peripheral.
- Acquisition tests cover data-ready timing, buffering, overruns, and sustained
  throughput.
- Storage tests cover full media, removal, write errors, fixed mux isolation,
  unmounting, and interrupted power.
- Long-duration tests cover timestamp drift, GNSS loss/reacquisition, queue
  pressure, and watchdog recovery.

## Implementation status

An empty source or header file counts as a scaffold, not as a defined interface
or implementation.

| Area | Scaffold present | Interface defined | Implemented | Hardware tested |
|---|---:|---:|---:|---:|
| Repository architecture and ignore rules | Yes | Yes | Yes | N/A |
| ESP-IDF project and build configuration | Partial | No | No | No |
| Common firmware status, error-context, and time types | Yes | Yes | Yes | N/A |
| `app_main` composition root | Yes | No | No | No |
| ESP32-S3 DevKit platform services | Partial | Partial | Partial | Partial |
| Rev-1 custom board integration | Yes | Partial | Partial | No |
| Application startup and shared types | Partial | Partial | Partial: acquisition data contracts, stopped-device configuration state, and radio-silent unattended field-recording control | Partial: configuration state exercised through Rev-1 UART; unattended start and BOOT-button close pending |
| Acquisition task | Yes | Partial | Partial: shared recording/live ADC lifecycle, minimal DRDY ISR, prepared two-buffer SPI-DMA bursts on core 1, a 256-frame capture ring, core-0 validation/DAT processing, independent fixed live-record pool, decimation, and explicit gap accounting | Partial: DRDY is armed only after ADC startup and recording waits for eight consecutive CRC-valid frames. A final 1 kSPS control retained every conversion. A two-second channels-0–3 16 kSPS SD probe retained 32,840 consecutive conversions at 16,000.04 conversions/s with zero gaps; intermediate presets, eight-channel 16 kSPS, live-stream limits, and long-duration behavior remain open. |
| Processing task | Yes | No | No | No |
| Storage task and fixed SD ownership | Yes | Yes | Fixed 40 MHz four-bit SDMMC/FatFs mount, catalog, create/write/sync/close/delete/read, failure cleanup, two 2 MiB PSRAM ping-pong buffers, and a 32 KiB internal SDMMC staging window | Partial: a 50-second four-channel 8 kSPS probe crossed two complete PSRAM-buffer boundaries while acquisition remained active; sampled boundary records were CRC-valid, status-OK, and sequence-contiguous. Reformatting the Cactus card from 4 KiB to 32 KiB FAT32 clusters reduced the observed 2 MiB boundary stall from 1.70–1.77 s to 0.274–0.303 s. Long-duration, injected-latency, and removal tests remain open |
| Communication task | Yes | Partial: startup, discovery, configuration, streaming, recording dispatch, complete DAT writes, and temporary file extraction | Partial: UART discovery, device configuration, live start/stop and bounded block ownership, all recording commands, and test-only `0xf000` closed-file reads | Partial: live start/stop, CRC-valid DAT delivery, disconnect expiry/reconnect, discovery/configuration, recording control, and stored-block extraction passed on Rev-1 |
| Bluetooth task | Yes | No | No | No |
| AD7779 driver | Yes | Partial | Partial: register map, lifecycle, hardware plus SPI reset, tolerant post-reset polling with strict response validation, expected reset acknowledgement, channel/gain/reference setup, synchronized fixed output-rate configuration, hardware-CS-framed prepared DMA capture callbacks, signed frame decoding, and header/status/pair-CRC validation | Partial: four-channel 16 kSPS throughput is gap-free at 20 MHz, but long captures expose isolated CRC-marked frame-phase errors. Fixed 8 MHz through 12 MHz miss the current full-frame deadline, fixed 16 MHz loses conversions during longer storage activity, and a hardware-CS-framed 20 MHz probe retained every conversion but still contained two phase errors. A shorter spec-compliant read path remains open; eight-channel coverage also remains open. |
| LSM6DSV driver | Yes | No | No | No |
| MAX-M10S driver | Yes | No | No | No |
| 74HC/HCT595 driver | Yes | Yes | Yes | No |
| Analog-card detection | Yes | Yes | Partial: bounded calibrated analog-ID measurement | Partial: slot 1 magnetic-card voltage |
| Magnetic analog card | Yes | Partial: independent SET/RESET pulse operation | Partial: callback-owned +18 V/output sequence with safe cleanup | Partial: Slot 1 SET and RESET commands passed on Rev-1; physical waveform remains unmeasured |
| Geophysical accelerometer card | Yes | No | No | No |
| Shared protocol specification | Yes | Defined in `protocol.md` | No | N/A |
| Portable ADC-record format | Yes | Defined in `protocol.md` | Complete encoder/validator plus shared Python decoder and golden vector | Native C/Python tests |
| Firmware protocol implementation | Yes | Partial: command frame, discovery, configuration, streaming, recording, magnetic pulse, and temporary extraction codecs | Partial: incremental `\CMD` parser, discovery/configuration/streaming/recording/pulse messages, and test-only `0xf000` file chunks | Partial: live start/stop plus interleaved DAT, discovery, configuration, recording commands, stored-block retrieval, acquisition-rail control, and magnetic SET/RESET exercised over Rev-1 UART; pulse waveform remains unmeasured |
| UART transport | Yes | Yes | Yes | Partial: 921600-baud discovery and configuration exchange |
| USB transport | Yes | No | No | No |
| Host application | Yes | Partial: discovery/configuration/streaming/recording/pulse/extraction codecs, mixed-stream parsing, capture, and desktop GUI | Partial: manual USB/COM connection, stopped-device ADC and acquisition-rail configuration, reported rail status, magnetic SET/RESET control, recording catalog/actions, SD-ready gating and asynchronous recording-failure reporting, separate embedded live plots, named replies during interleaved data, continuity counters, and byte-exact capture | Partial: desktop recording, live transport, reversible configuration, acquisition-rail switching, and magnetic SET/RESET command paths passed on Rev-1; pulse waveform and physical channel labels/calibration remain open |
| Developer diagnostics | Yes | Raw-record loading, validation, continuity summary, binary-to-CSV conversion, and plotting | Converts the portable 512-byte format to analysis-ready CSV and plots every recorded ADC channel without decimating FFT input | Converter and plotter covered by Python tests; plotting exercised with the `scratch/test_2` Rev-1 recording |
| Automated tests and continuous integration | Partial | Partial: protocol-vector tests | Partial: native C and Python discovery/configuration tests | N/A |

Update this table when an interface becomes usable, an implementation builds and
passes its software tests, or behavior has been verified on the Rev-1 hardware.

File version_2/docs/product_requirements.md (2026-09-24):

# Version 2 Product Requirements

> Historical planning document. This file is no longer authoritative. The
> current wire contract is defined only by `shared/protocol/protocol.md`.

## Document information

- Product version: V2
- Status: Historical; superseded
- Last updated: 2026-09-10
- Author: Benjamin Girard

## 1. Product scope and milestones

### Milestone 1: laboratory acquisition and validation

- Support both magnetic analog-card slots.
- Acquire three synchronized magnetic axes and one differential thermistor from each card.
- Acquire all eight AD7779 channels by default.
- Provide configurable ADC sample rate and per-channel gain.
- Stream live data to a PC through the ESP32 DevKit UART-to-USB connection.
- Reuse and adapt the V1 host application for visualization, validation, and host-side capture.
- Provide on-demand magnetic SET and RESET control for either card.
- Report protocol, acquisition, and hardware errors to the host.
- Boot and return to a safe hardware state.

Milestone 1 does not require SD recording, GNSS synchronization, IMU acquisition, Bluetooth, or
USB mass-storage access.

### Milestone 2: field recording and contextual sensors

- SD-card recording.
- MAX-M10S GNSS acquisition and inter-device time alignment.
- LSM6DSV IMU acquisition for orientation and movement detection.
- Geophysical accelerometer analog card.
- Bluetooth access to the same V2 commands and product features exposed by the
  wired interface, subject to the feature being implemented and available.
- Power-loss recovery and field-oriented fault handling.

### Explicitly unsupported in V2 Rev-1 firmware

- The USB2641 and USB connector will not provide SD-card mass-storage access.
- Firmware will not switch SD-card ownership between the ESP32 and USB2641.
- The SD mux will remain fixed to the ESP32 side. The USB2641 will remain reset/isolated.
- GNSS TIMEPULSE/PPS is not connected. A dedicated non-strapping GPIO is a future board-revision
  improvement.

## 2. ADC acquisition requirements

- ADC: AD7779.
- Resolution: signed 24-bit.
- Default output data rate: 1 kSPS per channel.
- Supported high-resolution output-rate presets: approximately 500 SPS, 1 kSPS, 2 kSPS, 4 kSPS,
  8 kSPS, and 16 kSPS per channel. Other rates and low-power mode are unsupported.
- Default active-channel mask: all eight channels.
- Channel assignment:
  - Channel 0: magnetic card 1, X axis.
  - Channel 1: magnetic card 1, Y axis.
  - Channel 2: magnetic card 1, Z axis.
  - Channel 3: magnetic card 1, differential thermistor.
  - Channel 4: magnetic card 2, X axis.
  - Channel 5: magnetic card 2, Y axis.
  - Channel 6: magnetic card 2, Z axis.
  - Channel 7: magnetic card 2, differential thermistor.
- All enabled channels from one AD7779 conversion form one indivisible sample frame.
- Unused or disabled channels are not transmitted or recorded.
- Per-channel gain is configurable.
- Supported gains: ×1, ×2, ×4, and ×8.
- Every frame carries a monotonically increasing sequence number.
- A frame may be rejected or marked invalid, but it must never disappear silently.
- ADC overrun and queue overflow counters are required.
- AD7779 status/header and CRC validation are required when enabled by the selected interface mode.
- The selected applied sample-rate preset must be reported.

The 16 kSPS requirement applies to ADC acquisition capability. The wired host interface is only
required to stream all eight raw 24-bit channels continuously at the default 1 kSPS rate. At higher
rates, the firmware may limit the streamed channel mask or send a decimated preview, but it must
report that behavior explicitly and must continue to detect acquisition overruns.

## 3. Analog bandwidth

- Input RF-filter cutoff: approximately 18.7 kHz.
- Servo time constant: approximately 14.1 s; its exact transfer function must be documented with
  the magnetic-card design.
- Anti-alias/filter cutoff: approximately 362 Hz.
- Anti-alias/filter order: first order.
- Primary signal frequency: approximately 2 Hz.
- Square-wave harmonics are scientifically relevant.
- Aliasing behavior at the default 1 kSPS rate must be measured during validation.

## 4. Synchronization and timestamps

### Milestone 1

- All eight channels in an ADC frame share one monotonic timestamp.
- X, Y, Z, and thermistor data from both magnetic cards come from the same simultaneous AD7779
  conversion frame.
- The timestamp represents the ADC conversion frame, not the time at which the host receives it.
- Absolute UTC time is not required for laboratory validation.

### Milestone 2

- MAX-M10S UART messages provide UTC and GNSS validity information.
- Rev-1 targets approximately 5 ms or better inter-device alignment using identical GNSS and UART
  configuration; this must be verified between two complete devices.
- Sub-millisecond absolute synchronization is not guaranteed without TIMEPULSE/PPS.
- When GNSS time is unavailable, acquisition continues using monotonic timestamps, absolute time
  is marked invalid, and a GNSS-loss event is recorded.
- When GNSS becomes valid again, the monotonic-to-UTC mapping is restored without changing or
  discontinuously rewriting existing sample timestamps.

## 5. Magnetic SET/RESET requirements

- SET and RESET operations are initiated only by an explicit user or diagnostic command.
- SET and RESET are never periodic background operations.
- SET and RESET for the same card must never be active simultaneously.
- The board API and magnetic-card driver both enforce mutual exclusion.
- Card 1 and card 2 can be addressed independently.
- A combined SET-then-RESET diagnostic sequence is supported only as an explicit on-demand
  command.
- Firmware control-pulse duration is a configurable board parameter initially constrained to the
  tens-of-microseconds to 100 µs range.
- The resulting current pulse through the sensor strap targets approximately 2–3 µs and must be
  verified with an oscilloscope before the operation is considered validated.
- A nonzero dead time is mandatory between SET and RESET. Use a conservative 100 ms default
  until bench measurements establish a lower safe value.
- Maximum consecutive operations and pulse-rail recharge time remain bench-derived limits. Until
  validated, firmware permits only one outstanding pulse operation at a time.
- Samples acquired during the firmware pulse, sensor-strap pulse, and post-pulse settling interval
  remain timestamped but are marked transient/invalid for scientific use.
- Post-pulse settling is configurable; use a conservative 10 ms initial value until measured.
- Every request records card slot, operation, command timestamp, actual pulse timestamp, result,
  and affected sample-sequence range.
- Pulse outputs remain inactive during boot, shutdown, unknown-card state, and fault handling.

## 6. Host streaming and application requirements

- Milestone 1 transport: ESP32 DevKit UART-to-USB connection.
- Default link baud rate: 921600 baud, subject to bench reliability.
- Required continuous stream: all eight packed 24-bit channels at 1 kSPS, plus framing and status.
- The host can select an alternate channel mask and supported ADC rate.
- When the requested stream exceeds transport capacity, firmware rejects it or negotiates an
  explicit reduced channel/preview configuration; it never silently drops data to fit the link.
- When Bluetooth is implemented in milestone 2, it exposes the same command semantics as UART.
  Its live stream may use an explicitly negotiated reduced channel mask, rate, or preview format
  when measured Bluetooth bandwidth cannot carry the full requested stream.
- The host application may save received laboratory data to the PC.
- Host-side data capture includes frame sequence numbers, timestamps, validity flags, and metadata.

Existing reference:

`magnetometer-node/firmware/esp32/ESP32-S3-WROOM-1/Mainboard/geophys-daq/tools/serial_scope.py`

Behavior to reuse:

- Serial-port selection and connection state.
- Live plotting for all magnetic axes and thermistors.
- FFT and signal statistics.
- ADC gain and rate controls.
- Channel selection.
- SET and RESET controls for either card.
- Host-side recording and gap indication.

Compatibility requirements:

- Compatibility with the legacy product's binary protocol is not required.
- A decoder for the shared wire protocol is required.
- A protocol-version and capability handshake is required.
- The handshake reports firmware version, protocol version, hardware revision, detected cards,
  available channels, supported gains/rates, and enabled features.
- Initial supported host OS: macOS 15.
- Windows portability is a milestone-2 goal; platform-specific logic should remain isolated.

## 7. Data representation and metadata

- Raw ADC values are represented on persistent or bandwidth-sensitive interfaces as packed signed
  24-bit samples.
- Byte order is fixed by the shared protocol specification.
- The ESP32 may sign-extend samples to `int32_t` internally.
- Default transmitted and, in milestone 2, recorded channel mask: all eight channels.
- Thermistor channels are acquired and transmitted at the same rate as their corresponding magnetic
  axes by default.
- AD7779, IMU, and ESP32 internal temperature readings are separate low-rate housekeeping records,
  nominally produced every 10 seconds when their source is available.
- Required metadata:
  - Firmware and protocol version.
  - Hardware revision.
  - Card type and revision for each slot.
  - Active-channel mask and channel-to-sensor mapping.
  - Requested and actual sample rate.
  - ADC gain per channel.
  - ADC reference configuration.
  - Start monotonic timestamp.
  - UTC start time and GNSS validity when available.
  - Calibration identifier.
  - Reset reason and error counters.

## 8. Milestone-2 SD recording requirements

- Default recorded channels: all eight ADC channels.
- Expected continuous recording duration: 15 minutes to 8 hours at the default 1 kSPS rate.
- Current development SD-card capacity: 8 GB.
- The required eight-channel 1 kSPS packed payload is approximately 86.4 MB/hour before framing
  and metadata, and therefore fits comfortably for eight hours on an 8 GB card.
- Eight channels at 16 kSPS require approximately 1.38 GB/hour before overhead and are not required
  to fit for eight hours on an 8 GB card.
- Filesystem: FAT32.
- Segmentation: create a new file after one hour or 1 GiB, whichever occurs first.
- File names use UTC start time when valid, plus device identifier and sequence number. Before UTC
  is available, use boot identifier and sequence number.
- On orderly shutdown, queued data is flushed, the file is closed, and the filesystem is unmounted.
- Following power loss, completed segments remain readable. On the next boot, firmware detects and
  reports an incomplete final segment and applies a documented recovery/truncation procedure.
- Recording resumes in a new segment rather than appending to a potentially damaged segment.
- If the SD card is missing, removed, full, or fails, acquisition may continue for host streaming but
  recording stops and an error event is reported.

## 9. SD mux and USB2641 policy

- The SD mux is configured once for ESP32 ownership and is not switched at runtime.
- The USB2641 remains reset/isolated and never owns the SD card.
- USB mass-storage export is unsupported on V2 Rev-1.
- USB serial host communication through the ESP32 DevKit remains supported and is independent of
  the USB2641/SD path.
- Firmware does not implement ESP32-to-USB2641 or USB2641-to-ESP32 transition state machines.

## 10. Fault and error behavior

All errors have a stable error code, a timestamp, a severity, and relevant counters or context. Errors
are emitted through the shared protocol when the host is connected and are included in milestone-2
recordings.

| Fault | Required response | User-visible indication | Automatic recovery |
|---|---|---|---|
| ADC not detected or initialization fails | Keep acquisition stopped and pulse outputs inactive | Error event and status | Retry only by explicit reinitialize command or reboot |
| ADC CRC/header error | Mark affected frame invalid; increment counter | Frame flag and error counter | Continue after isolated errors; reinitialize the ADC if frame synchronization is lost |
| ADC or queue overrun | Preserve sequence discontinuity; increment dropped-frame count | Gap event and counter | Continue if buffers recover; otherwise stop stream cleanly |
| Magnetic card missing or removed | Disable that slot's SET/RESET controls; invalidate its channel mapping | Card-state event | Re-detect only while acquisition is stopped |
| Unsupported stream request | Reject without altering current configuration | Command error containing supported limits | Host may submit a supported request |
| Host disconnect | Stop acquisition cleanly and clear any pending pulse command | Disconnect event when detectable; reconnect status includes prior counters | Reconnect and restart without reboot when safe |
| SD missing/full/write failure (milestone 2) | Stop recording, close/unmount when possible, continue acquisition if possible | Error event | Explicit user action required |
| GNSS unavailable (milestone 2) | Continue monotonic acquisition; absolute time invalid | GNSS validity event | Restore mapping when valid data returns |
| Brownout or unexpected reset | Hardware returns to safe outputs; previous reset reason retained | Startup status event | Normal safe initialization |

Errors are never reported by silently corrupting, reordering, or omitting the ADC frame sequence.

## 11. Milestone-1 acceptance criteria

- [ ] Firmware boots with power rails, pulse controls, and shared outputs in their documented safe
      states.
- [ ] Each magnetic card is independently detected in either slot.
- [ ] Both magnetic cards can be present and operated simultaneously.
- [ ] AD7779 initializes and reports its configuration successfully.
- [ ] All eight channels acquire synchronously at the default 1 kSPS rate.
- [ ] Each frame has one monotonic timestamp, sequence number, validity flags, and AD7779 status.
- [ ] The ADC can be configured for each supported preset through 16 kSPS and reports the selected
      applied preset.
- [ ] All eight channels stream continuously to the host at 1 kSPS for eight hours with no unexplained
      gaps or silent frame loss.
- [ ] Intentional errors, CRC failures, and overruns are visible through counters or protocol events.
- [ ] Manual SET and RESET work independently for either card and can never overlap.
- [ ] Sensor-strap pulse width is measured at approximately 2–3 µs.
- [ ] Pulse-affected and settling samples are identified by their frame-sequence range.
- [ ] The V2 handshake and data stream are decoded by the reused host application.
- [ ] The host displays both cards, reports gaps, changes gain/rate, and saves laboratory captures.

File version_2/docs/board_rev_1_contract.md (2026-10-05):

# Rev-1 Board Firmware Contract

## Document information

- Status: Draft
- PCB revision: V2-Rev-1
- Schematic project:
  `version_2/hardware/pcb/rev_1/mainboard_v2_r1/`
- Compute platform: ESP32-S3 DevKitC
- Schematic revision/date: 2026-07-23
- Last updated: 2026-10-01

## 1. ESP32 peripheral assignments

| Function | ESP32 peripheral | Pins | Frequency/baud | DMA | Owner | Verification |
|---|---|---|---:|---|---|---|
| AD7779 SPI | SPI2 | SCLK:GPIO12, MOSI/SDI:GPIO13, MISO/SDO:GPIO14, CS:GPIO11 | Fixed 20 MHz, mode 0; external MCLK: 8.192 MHz | Yes | `task_acquisition` | Hardware frames each prepared 32-byte DMA burst with CS; throughput passes at 16 kSPS, but conversion integrity remains open |
| AD7779 control | 74HC595 #2 | RESET:SH2_C, START:SH2_D, MCLK_EN:SH2_E, CONVST_SAR:SH2_F | - | No | `task_acquisition` through `board` | Schematic |
| 74HC595 chain | GPIO bit-bang | SHCP:GPIO19, STCP:GPIO20, DS:GPIO47, OE_N:GPIO21 | Initial 1 us between driver transitions; conservative limit ≤4 MHz | No | `board` | Schematic + Nexperia 74HC595 Rev. 12 datasheet |
| LSM6DSV SPI | SPI3 | SCLK:GPIO17, MOSI:GPIO18, CS:GPIO46, MISO:GPIO9 | ≤10 MHz | No | `task_imu` | Schematic + datasheet |
| MAX-M10S UART | UART1 | ESP32 RX:GPIO45, ESP32 TX:GPIO48 | Target: 921600 baud | No | `task_gnss` | Schematic; bench open |
| Card-slot 1 I²C / GPIO | I2C0 or GPIO | GPIO40, GPIO41 | [TBD] | No | `card_detect` / selected card driver | Schematic |
| Card-slot 2 I²C / GPIO | I2C1 or GPIO | GPIO38, GPIO39 | [TBD] | No | `card_detect` / selected card driver | Schematic |
| SD card | SDMMC host | CMD:GPIO16, CLK:GPIO7, D0:GPIO5, D1:GPIO4, D2:GPIO15, D3:GPIO6 | 40 MHz high-speed, 4-bit | Yes | `task_storage` | Schematic; Rev-1 mount/catalog and high-speed recording bench pass |
| Debug/host UART | UART0 | TX:GPIO43, RX:GPIO44 (DevKit default) | Default: 921600 baud, 8-N-1, no flow control; higher rates configurable while stopped | N/A | `task_communication` | DevKit assignment; bench open |

## 2. Direct ESP32 signals

| Signal | GPIO | Direction | Active level | Physical pull | Boot state | Safe state | Owner | Timing/interrupt | Verification |
|---|---:|---|---|---|---|---|---|---|---|
| `ADC_DRDY` | GPIO10 | Input | Low | None | Input | Input | `task_acquisition` | Falling-edge interrupt | Schematic + datasheet |
| `ADC_CS` | GPIO11 | Output | Low | Pull-up, 10 kΩ | High | High | `task_acquisition` | SPI hardware asserts Low only for each transaction and returns High immediately afterward | Schematic + Rev-1 bench |
| `DEVICE_DETECT_1` | GPIO3 | Analog input | Analog ID voltage | Pull-up, 10 kΩ to 3.3 V | Input; strapping sampled | Input | `card_detect` | Sample and average at startup | Schematic |
| `DEVICE_DETECT_2` | GPIO8 | Analog input | Analog ID voltage | Pull-up, 10 kΩ to 3.3 V | Input | Input | `card_detect` | Sample and average at startup | Schematic |
| `SR_SHIFT_CLK` | GPIO19 | Output | Rising edge | None | USB Serial/JTAG default | Low after claimed | `board` | No clock edges while changing ownership | Schematic |
| `SR_DATA` | GPIO47 | Output | N/A | None | Input/high impedance | Low after claimed | `board` | Stable before shift-clock edge | Schematic |
| `SR_OE_N` | GPIO21 | Output | Low enables outputs | Pull-up, 10 kΩ | High | High until safe image is latched | `board` | Enable last; disable first | Schematic |
| `SR_LATCH` | GPIO20 | Output | Rising edge | None | USB Serial/JTAG default | Low after claimed | `board` | Pulse only after complete 16-bit image | Schematic |
| `SOLAR_PRESENT` | GPIO1 | Input | Low | Pull-up, 100 kΩ | Input | Input | `board` | - | Schematic |
| `5V_USB_PRESENT` | GPIO2 | Input | Low | Pull-up, 100 kΩ | Input | Input | `board` | Debounce [TBD] | Schematic |
| DevKitC `BOOT` button | GPIO0 | Input | Low | DevKitC pull-up + ESP32 pull-up | Boot strap, then input | Input | `board` | Three-second hold requests clean field-recording stop | DevKitC hardware |
| `EN_SUPERCAP_CHARGE` | GPIO42 | Output | [TBD] | None | Input/high impedance | Inactive level [TBD] | `board` | Power-policy controlled | Schematic; polarity open |

## 3. Shift-register output assignments

The two 74HC595 devices form one shared 16-bit resource. Only the `board` module may write the
physical chain or its shadow image. Tasks and card drivers request logical output changes through
the board API so unrelated bits cannot overwrite one another.

| Output | Signal | Active level | Physical pull | Electrical boot state while `SR_OE_N` is high | Required safe state | Logical owner | Verification |
|---|---|---|---|---|---|---|---|
| SH1_A | `SD_MUX_SEL` | Selector: Low = ESP32; High = USB2641 | Pull-down, 10 kΩ | Low; ESP32 selected | Low; ESP32 selected | `board` | Schematic + mux datasheet |
| SH1_B | `EN_LDO_3V3` | High enables | Device-internal pull-down | Low; disabled | Low; disabled | `board` | Schematic + regulator datasheet |
| SH1_C | `EN_BST_10V` | High enables | Pull-down, 100 kΩ | Low; disabled | Low; disabled | `board` | Schematic + regulator datasheet |
| SH1_D | `EN_BST_18V` | High enables | Pull-down, 100 kΩ | Low; disabled | Low; disabled | `board` | Schematic + regulator datasheet |
| SH1_E | `EN_INV_-5V` | High enables | None external | Undefined if the regulator input supply is present | Low; disabled | `board` | Schematic + regulator datasheet; boot level not bench tested |
| SH1_F | `USB2641_nRESET` | Low asserts reset | Pull-up, 10 kΩ | High; reset released | Low; USB2641 held reset/isolated | `board` | Schematic + USB2641 datasheet |
| SH1_G | `EN_SD_MUX` | Low enables mux; High disconnects all channels | Pull-up, 100 kΩ | High; mux disabled | Low; mux enabled on ESP32 path | `board` | Schematic + mux datasheet |
| SH1_H | `EN_LED` | High enables | Gate pull-down, 100 kΩ | Low; disabled | Low; disabled | `board` | Schematic |
| SH2_A | `RESET_2` | High pulse request | Pull-down, 100 kΩ | Low; inactive | Low; inactive | Selected card driver | Schematic + reused magnetic-card design; bench open |
| SH2_B | `SET_2` | High pulse request | Pull-down, 100 kΩ | Low; inactive | Low; inactive | Selected card driver | Schematic + reused magnetic-card design; bench open |
| SH2_C | `ADC_RESET` | Low asserts reset | Pull-up, 100 kΩ | High; reset released | Low; reset asserted | `task_acquisition` | Schematic + AD7779 datasheet |
| SH2_D | `ADC_START` | Low synchronization pulse; idle High | Pull-down, 100 kΩ | Low; synchronization asserted | High; inactive | `task_acquisition` | Schematic + AD7779 datasheet |
| SH2_E | `ADC_MCLK_EN` | High or floating enables clock output | Pull-up, 100 kΩ | High; clock enabled | Low; clock disabled | `task_acquisition` | Schematic + oscillator datasheet |
| SH2_F | `ADC_CONVST_SAR` | Rising edge/High pulse requests conversion | Pull-down, 100 kΩ | Low; inactive | Low; inactive because SAR is unused | `task_acquisition` | Schematic + AD7779 datasheet |
| SH2_G | `RESET_1` | High pulse request | Pull-down, 100 kΩ | Low; inactive | Low; inactive | Selected card driver | Schematic + reused magnetic-card design; bench open |
| SH2_H | `SET_1` | High pulse request | Pull-down, 100 kΩ | Low; inactive | Low; inactive | Selected card driver | Schematic + reused magnetic-card design; bench open |

### Safe 16-bit image

The serialized image uses SH1_A through SH1_H as bits 15 through 8 and SH2_A through SH2_H as
bits 7 through 0. Bit 0 is shifted first because it must travel through both 74HC595 devices.

The canonical safe image is `0x0010`. Only SH2_D / `ADC_START` is High. This image:

- selects and enables the fixed ESP32 SD path;
- holds the USB2641 in reset;
- disables the analog rails, pulse supply, ADC master clock, SAR request, and LED;
- holds the AD7779 in reset with `ADC_START` inactive; and
- holds every SET/RESET request inactive.

The resistor-defined states while `SR_OE_N` is High are not equivalent to this safe image. In
particular, the USB2641 reset is released, the ADC reset is released, `ADC_START` is Low, and the
ADC oscillator is enabled until the safe image is latched and the 74HC595 outputs are enabled.

## 4. ESP32 pin restrictions and Rev-1 limitations

- GPIO3, GPIO45, and GPIO46 are ESP32-S3 strapping pins used by this board.
- GPIO3 is also `DEVICE_DETECT_1`. Its card-divider voltage is present while the ESP32 samples its
  strapping pins, before firmware can configure or average the ADC input. Verify cold boot and
  firmware download with no card and with each defined identification resistor in slot 1.
- GPIO45 is the MAX-M10S-to-ESP32 receive line and also selects the ESP32-S3 `VDD_SPI`
  strapping state. Verify the voltage on GPIO45 through power-up and reset while the GNSS board
  is connected and powered.
- GPIO46 is the LSM6DSV chip-select output and participates in boot/download-mode selection.
  The LSM6DSV `CS` input has an internal 30-50 kOhm pull-up that opposes the ESP32-S3 weak
  pull-down during reset. Rev-1 bench testing confirmed unreliable firmware download as a result.
  The Rev-1 workaround is to hold GPIO46 Low while the boot straps are sampled; firmware cannot
  correct this because it starts afterward.
- GPIO19 and GPIO20 are used for shift-register clock/latch, so the ESP32 USB Serial/JTAG
  function is unavailable once these pins are claimed by firmware.
- GPIO39 through GPIO42 overlap the default JTAG pins. Card-slot signals and supercapacitor
  control therefore make hardware JTAG unavailable in normal operation.
- MAX-M10S TIMEPULSE is not connected in Rev-1. Rev-1 uses UART-only GNSS synchronization,
  targets approximately 5 ms or better inter-device alignment, and requires bench verification.
  Sub-millisecond synchronization is not guaranteed. A dedicated non-strapping TIMEPULSE GPIO
  is reserved as a Rev-2 improvement.
- Rev-2 must move `CS_LSM` from GPIO46 to a non-strapping GPIO. A permanent strong pull-down on
  GPIO46 is only a Rev-1 rework option, not the preferred Rev-2 correction.

## 5. Verification terminology

- **Schematic:** the net or assignment was checked in the KiCad schematic only.
- **Datasheet:** polarity, limits, or timing were checked against the component datasheet.
- **Bench:** behavior was measured on assembled hardware.
- **Open:** the item has not yet been resolved.

`Schematic` verification does not imply that the signal has been electrically tested.

### Milestone-1 blocking decisions

Not every open value prevents the first firmware work. The following gates identify when each
hardware decision becomes mandatory.

| Gate | Values that must be resolved | Blocks |
|---|---|---|
| Before enabling 74HC595 outputs | Active polarity and safe level of every SH1/SH2 signal; complete safe 16-bit image; fixed `SD_MUX_SEL`, `EN_SD_MUX`, and `USB2641_nRESET` levels | Rev-1 `board_init()` and any powered hardware test |
| Before driving `EN_SUPERCAP_CHARGE` | Active polarity, boot-safe level, and allowed power policy | Supercapacitor-charge control; keep GPIO high impedance until resolved |
| Before starting AD7779 acquisition | Analog-rail enable polarities/order/settling; `ADC_MCLK_EN` and `ADC_START` levels; reset/clock timing; conservative SPI clock | ADC initialization and acquisition bench test |
| Before accepting card detection | Detect resistor network, no-card and magnetic-card voltage windows, sampling/averaging policy, and hot-plug policy | Automatic card identification and slot availability |
| Before enabling SET/RESET commands | SET/RESET active levels, firmware control width, 18 V settling/recharge limits, minimum interval, and post-pulse settling | Magnetic pulse feature; acquisition may proceed with pulses disabled |
| Before claiming reliable Rev-1 boot | GPIO45 and GPIO46 strapping behavior with attached GNSS/IMU hardware | Hardware-validation sign-off; these milestone-2 devices remain uninitialized in milestone 1 |

SDMMC clock/DMA settings, GNSS timing, IMU configuration, and SD recording behavior do not block
milestone-1 UART acquisition. They remain milestone-2 work.

## 6. Power rails

| Rail | Control signal | Active level | Supplies | Default | Required before | Settling time | Fault indication |
|---|---|---|---|---|---|---|---|
| `3V3A` | SH1_B / `EN_LDO_3V3` | High | ADC/card analog circuitry [TBD] | Off | ADC/card init | 100 ms initial value | [TBD] |
| `10V` | SH1_C / `EN_BST_10V` | High | Upstream supply for 9VA [verify] | Off | 9VA | 100 ms initial value | [TBD] |
| `9VA` | Derived from 10V; no independent shift-register output | N/A | ADC/reference and magnetic bridge [TBD] | Follows 10V path | Magnetic acquisition | Included in 10 V wait | [TBD] |
| `-5VA` | SH1_E / `EN_INV_-5V` | High | Analog circuitry | Off | Magnetic acquisition | 100 ms initial value | [TBD] |
| `18V` | SH1_D / `EN_BST_18V` | High | Pulse circuitry | Off; enabled on demand only | SET/RESET | 100 ms before pulse | [TBD] |

The initial delays are deliberately conservative. Their purpose is to avoid simultaneous rail startup
and large combined inrush, not to meet a known tight device requirement. Rev-1 bench measurements may
shorten them later without changing the sequence or ownership model.

After the per-rail delays, firmware waits an additional 1,000 ms with `3V3A`, `10V`/`9VA`, and
`-5VA` enabled before initializing the AD7779. This gives the magnetic-sensor feedback loop time to
settle before ADC startup so the observed initial peak can decay before acquisition data begins.

## 7. Power-up sequence

| Step | Action | Delay/condition | Verification | Failure response |
|---:|---|---|---|---|
| 1 | Configure direct control GPIOs safely | Immediate | [TBD] | Remain safe |
| 2 | Disable shift-register outputs | Immediate | `SR_OE_N` inactive | Remain safe |
| 3 | Load safe shift-register image `0x0010` | Before enabling outputs | Confirm 16-bit shadow state | Remain safe |
| 4 | Enable shift-register outputs | Safe image already latched | `SR_OE_N` active | Remain safe |
| 5 | Detect both analog cards | Average each ID input for the startup detection window | Stable classification | Keep card controls inactive |
| 6 | Enable `3V3A` when required | Wait 100 ms | [TBD] | Disable controlled rails |
| 7 | Enable `10V`, producing the derived 9VA path | Wait 100 ms | [TBD] | Disable controlled rails |
| 8 | Enable `-5VA` | Wait 100 ms | [TBD] | Disable controlled rails |
| 9 | Let the magnetic-sensor feedback loop settle with all acquisition rails enabled | Wait 1,000 ms | Inspect startup peak and ADC status in a recording | Disable controlled rails |
| 10 | Enable ADC master clock | Wait at least 5 ms | Clock detected | Disable ADC |
| 11 | Reset and initialize AD7779 | Use the initial sequence below | Status/identity checks | Report ADC fault |
| 12 | Initialize the detected magnetic card | After required rails are stable | Card available | Mark unavailable |
| 13 | Start acquisition when requested | Command | DRDY active | Report failure |

The 18 V rail is not part of normal acquisition startup. It remains off until an on-demand SET or
RESET request, then is enabled and allowed to settle for 100 ms before the pulse.

### Initial AD7779 control and SPI baseline

The first Rev-1 implementation uses the electrically proven V1 settings as a conservative baseline:

| Parameter | Initial Rev-1 value |
|---|---|
| SPI host and format | SPI2, full duplex, mode 0, MSB first |
| SPI clock | Fixed 20 MHz for initialization, configuration, and conversion-frame reads |
| Chip select | GPIO11, SPI-peripheral controlled, active Low; one independent CS pulse per transaction |
| CS timing margin | One SCLK cycle before and after each transaction (50 ns at 20 MHz), exceeding the datasheet's 10 ns minima |
| Transfer context | Register access uses bounded synchronous transfers. Acquisition reserves SPI2 once and advances prepared 32-byte polling-start/polling-end DMA bursts from the core-1 acquisition task. Hardware CS adds no task-context GPIO operation or delay; the DRDY ISR performs no SPI work. |
| Master clock | Set `ADC_MCLK_EN` High, then wait at least 5 ms |
| ADC power mode | High-resolution mode only |
| ADC reference | External REF1/REF2 selection using the board-filtered internal `REF_OUT`; keep the reference-output buffer enabled |
| Hardware reset | Hold `ADC_RESET` Low for 2 ms, release High, then wait at least 10 ms |
| START | Hold Low through clock/reset startup, then drive High and leave High when inactive |
| CONVST_SAR | Keep Low because milestone 1 does not use the SAR ADC |
| Reset method | Hardware `ADC_RESET` pulse followed by the datasheet-defined SPI software reset (SDI High for 64 SCLKs), then a 5 ms settling margin inherited from the working V1 implementation |
| Initialization check | Poll `INIT_COMPLETE` for up to 500 ms; tolerate malformed/stale register responses during that window, but require a valid `0x20` response header before proceeding |
| Configuration synchronization | Toggle `SPI_SYNC` Low, wait 10 us, return it High, then discard 5 ms of settling time before enabling SPI conversion readback; margins inherited from the working V1 implementation and pending Rev-1 waveform verification |
| Startup conversion policy | Keep DRDY disabled through reset, synchronization, SRC update, and filter settling. After `ad7779_start()`, discard interface startup frames until eight consecutive frames pass the AD7779 data CRC; scientific DAT production begins with the eighth valid frame. |

The V1 AD7779 register definitions, CRC handling, configuration sequence, and frame decoding are
working references. They must be adapted to the V2 architecture: the portable AD7779 driver remains
free of ESP-IDF and FreeRTOS, while the ESP32 platform supplies the SPI transaction and GPIO/interrupt
mechanisms. The V1 dedicated streaming task inside its hardware adapter is not an architectural
precedent for V2.

## 8. Power-down sequence

| Step | Action | Delay/condition | Verification |
|---:|---|---|---|
| 1 | Stop acquisition | [TBD] | No pending ADC transaction |
| 2 | Place pulse controls inactive | [TBD] | Safe-state image |
| 3 | Stop ADC/clock | [TBD] | [TBD] |
| 4 | Disable analog rails | [TBD] | [TBD] |
| 5 | Disable card power | [TBD] | [TBD] |
| 6 | Retain required keepalive state | [TBD] | [TBD] |

## 9. Fixed SD/USB policy

V2 Rev-1 has no runtime SD ownership transitions. The board initializes this path once and does
not expose an API for selecting the USB2641 side.

| State | ESP32 SDMMC | USB2641 | Mux selection | Filesystem |
|---|---|---|---|---|
| Boot/safe initialization | High impedance | Assert reset as soon as the safe image is applied | `SD_MUX_SEL` Low and `EN_SD_MUX` Low | Unmounted |
| Milestone-1 runtime | Not initialized | Reset/isolated | Fixed to ESP32 | Unmounted |
| Milestone-2 recording | Enabled when storage starts | Reset/isolated | Fixed to ESP32 | Mounted by ESP32 |
| Storage fault | Disabled or stopped safely | Reset/isolated | Remains fixed to ESP32 | Unmounted when possible |

Initialization requirements:

1. Keep shift-register outputs disabled while loading the safe image.
2. Set `SD_MUX_SEL` Low to select the ESP32 normally closed path.
3. Set `USB2641_nRESET` Low to assert reset.
4. Set `EN_SD_MUX` Low to enable the selected ESP32 path.
5. Enable shift-register outputs only after all other SH1/SH2 bits are safe.
6. Never change these three SD/USB control bits during normal runtime.

Firmware implementation requirements:

- Encode these three fixed values in the Rev-1 board configuration and in the canonical safe image;
  application code must not know their shift-register positions or electrical levels.
- `board_init()` applies the complete safe image before enabling the 74HC595 outputs.
- Every later shift-register update preserves `SD_MUX_SEL = Low`, `EN_SD_MUX = Low`, and
  `USB2641_nRESET = Low`; `board_enter_safe_state()` reasserts the same values.
- Do not expose a board API for changing SD ownership, disabling the ESP32 mux path, or releasing
  the USB2641 reset.
- The recording firmware initializes SDMMC and mounts FatFs without formatting.
  The USB2641 remains reset and isolated throughout.

The fixed logic levels are resolved from the schematic and mux/USB2641 datasheets. Any required
initial settling delay before milestone-2 SDMMC initialization remains a bench item. Break-before-make
timing is not a firmware requirement because runtime ownership switching is unsupported.

## 10. Analog-card detection

- Detection signals: `DEVICE_DETECT_1` on GPIO3 and `DEVICE_DETECT_2` on GPIO8.
- Signal type: analog identification voltage; binary active level is not applicable.
- Physical resistor network: 10 kΩ pull-up to 3.3 V on the mainboard and one card-identification
  resistor from the detect signal to ground on the expansion card.
- Detection at startup: Yes, before enabling the controlled analog rails.
- Hot-plug supported: No for milestone 1; changing a card requires a restart.
- Sampling/averaging interval: initial target is 2 seconds at 100 samples/s per slot. Use a median or
  trimmed mean so a small number of startup outliers cannot determine the card type. Configure the
  ESP32 ADC input range to cover 3.3 V and use its calibration support when converting to millivolts.
- Power allowed before identification: fixed 3.3 V digital supply only; controlled analog and pulse
  rails remain off.
- Behavior when removed during acquisition: unsupported in milestone 1; detailed fault detection is
  deferred because the ID inputs are not monitored continuously.
- Behavior for unknown or ambiguous voltage: keep card controls and controlled rails inactive for
  that slot and report the measured voltage to the host.

For a 3.3 V pull-up supply, the expected divider voltage is
`3.3 V × R_card / (10 kΩ + R_card)`. Initial classification boundaries are the midpoints between
the nominal voltages. These thresholds are suitable for first firmware but remain subject to calibrated
ESP32 ADC and assembled-card measurements.

| Card state/type | Card resistor to ground | Nominal detect voltage | Initial accepted minimum | Initial accepted maximum | Milestone-1 handling |
|---|---:|---:|---:|---:|---|
| No card | Open circuit | 3.30 V | 2.750 V | ADC full scale | Leave slot inactive |
| Magnetic card | 20 kΩ | 2.20 V | 1.925 V | 2.750 V | Initialize `card_magnetic` |
| Accelerometer card | 10 kΩ | 1.65 V | 1.375 V | 1.925 V | Identify and report; driver deferred |
| Resistivity card | 5 kΩ | 1.10 V | 0.550 V | 1.375 V | Identify and report; driver deferred |
| Unknown/invalid | Short, out-of-range, or unstable | N/A | Outside accepted ranges | Outside accepted ranges | Keep slot inactive and report voltage |

## 11. Magnetic SET/RESET sequence

| Parameter | SET | RESET |
|---|---:|---:|
| Control signal | `SET_1` (SH2_H) or `SET_2` (SH2_B), according to slot | `RESET_1` (SH2_G) or `RESET_2` (SH2_A), according to slot |
| Active level | High pulse; Low inactive | High pulse; Low inactive |
| Pulse width | Initial value: 200 us; bench verification required | Initial value: 200 us; bench verification required |
| Pre-pulse delay | 100 ms after enabling the 18 V rail | 100 ms after enabling the 18 V rail |
| Post-pulse settling | [TBD by ADC observation] | [TBD by ADC observation] |
| Required rail | 18 V pulse rail, enabled only for the request | 18 V pulse rail, enabled only for the request |
| Repetition policy | On demand only; no periodic operation; minimum interval [TBD] | On demand only; no periodic operation; minimum interval [TBD] |

The initial timing values come from the working V1 `hmc100x` implementation. They are starting
values, not Rev-1 verification evidence. V1 used a 10 ms interval in its combined diagnostic, in
the order RESET then SET. The V2 interface currently describes that diagnostic in the opposite
order, so a combined operation must not be implemented until its required order and measurement
purpose are resolved. Independent on-demand SET and RESET requests are unaffected by this question.

The V1 default left the 9VA magnetic-bridge supply enabled during a pulse. V2 follows that behavior:
the pulse sequence does not cycle the normal acquisition rails. The V1 periodic task, direct access
to shift-register bits, simultaneous selection of both slots, and policy of leaving the 18 V rail on
are not architectural precedents for V2.

Sequence:

1. Confirm that a magnetic card is present in the requested slot.
2. Acquire the acquisition/pulse resource and reject overlapping pulse requests.
3. Through the board API, force SET and RESET inactive for both slots.
4. Mark acquisition state as pulse/transient before switching the pulse rail.
5. Enable the 18 V pulse rail and wait 100 ms.
6. Assert only the requested slot and operation for an initial 200 us.
7. Return the pulse output inactive, then disable the 18 V rail.
8. Wait for the bench-defined analog settling interval while samples remain transient.
9. Resume normal sample-valid state.
10. Record the requested operation, actual timing, affected frames, and result.

SET and RESET must never be active simultaneously. Samples acquired during the pulse and
post-pulse settling interval remain timestamped but are marked transient/invalid for scientific use.
Every success, failure, timeout, and abort path must leave all SET/RESET outputs Low and the 18 V
rail disabled. `task_acquisition` owns command serialization and sample-validity timing.
`analog_cards/magnetic` owns the card-specific pulse generation, including pulse width, ordering,
dead time, and settling policy. It requests the 18 V rail and logical SET/RESET state through bound
callbacks. Only the Rev-1 `board` module controls the mainboard 18 V rail and translates those
logical requests into shift-register changes. `analog_cards/acc_geoph` has no SET/RESET behavior.

## 12. Open hardware questions

| Question | Responsible person | Source | Status |
|---|---|---|---|
| Does the MAX-M10S TX level on GPIO45 preserve the required ESP32 `VDD_SPI` strap during every reset condition? | Hardware | Schematic + oscilloscope | Open |
| GPIO46/LSM6DSV CS pull-up prevents reliable firmware download without holding GPIO46 Low during strap sampling | Hardware/firmware | Schematic + LSM6DSV datasheet + boot test | Confirmed Rev-1 issue; move `CS_LSM` to a non-strapping GPIO in Rev-2 |
| Do the no-card, 20 kΩ, 10 kΩ, and 5 kΩ slot-1 detection states preserve the required GPIO3 strap behavior? | Hardware/firmware | Repeated cold boot and download test | Open |
| Do the assembled-board SH1/SH2 boot and safe levels match the schematic/datasheet-derived contract, especially floating `EN_INV_-5V`? | Hardware | Oscilloscope/logic analyzer | Open |
| Does the assembled unit's shift-register control wiring match the checked-in Rev-1 netlist (`DATA=GPIO47`, `OE_N=GPIO21`, `LATCH=GPIO20`, `SHIFT_CLK=GPIO19`)? The V1 firmware port swaps these four assignments. | Hardware/firmware | Continuity test plus shift-clock/latch logic-analyzer capture | Open; resolve before treating the V1 image as a definitive ADC comparison |
| Do the assembled-card divider voltages fall inside the initial identification windows with adequate margin? | Hardware | Calibrated ESP32 ADC + multimeter | Open |
| Does the initial 200 us SET/RESET pulse provide the required current and duration, and what minimum request interval and post-pulse analog settling time are safe? | Hardware | V1 reference + magnetic-card design + oscilloscope/ADC data | Open |
| What startup settling delay, if any, is required before SDMMC initialization? | Hardware | Repeated cold-start mount test + logic analyzer if failures occur | Open; one clean-build mount passed without an explicit delay |
| What is the safe boot level and policy for `EN_SUPERCAP_CHARGE`? | Hardware | Schematic + power test | Open |
| Does fixed 20 MHz, mode-0 AD7779 SPI with one hardware-generated CS pulse per transaction operate reliably on the assembled Rev-1 board? | Firmware/hardware | ADC register and recording tests | No. It sustains 16 kSPS without gaps, but a two-second hardware-CS probe still contained two CRC-marked channel/byte phase errors. The 20 MHz read clock remains above the conservative limit implied by worst-case SDO timing. |
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

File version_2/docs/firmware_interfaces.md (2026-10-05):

# Version 2 Firmware Interface Contract

## Document information

- Status: Active interface guide; wire details defer to `shared/protocol/protocol.md`
- Product version: V2
- Initial target: two magnetic cards, eight synchronized AD7779 channels
- Last updated: 2026-10-01

## 1. Purpose and implementation scope

This document defines ownership and interface rules between firmware modules. It is intentionally
small: an interface exists only when it prevents duplicated hardware access, hidden coupling, or
ambiguous data.

The first runnable acquisition slice uses:

- `task_acquisition`
- `task_communication`
- Rev-1 `board`
- AD7779, 74HC595, card-detection, and magnetic-card modules
- UART transport and the shared protocol

Storage, GNSS, IMU, processing, and Bluetooth may remain scaffolded until their
implementation phase. Their host-visible command meanings are nevertheless
already fixed by `shared/protocol/protocol.md`.

## 2. Dependency and access rules

- Component drivers contain no ESP-IDF, FreeRTOS, board GPIO, application, or protocol types.
- The ESP32 platform layer implements generic SPI, I²C, UART, GPIO, interrupt, and monotonic-time
  mechanisms.
- `boards/rev_1` contains all Rev-1 wiring, active levels, safe states, power sequencing, shift-register
  mapping, and component instances.
- Analog-card modules describe a card as a product component but never manipulate raw GPIO numbers
  or shift-register bits.
- `analog_cards/magnetic` owns the magnetic SET/RESET pulse-generation sequence and its card-specific
  timing. It requests 18 V rail and logical SET/RESET output changes through callbacks supplied by
  `boards/rev_1`.
- `analog_cards/acc_geoph` does not implement or expose magnetic SET/RESET operations.
- Application tasks use board, card, and protocol interfaces. They do not call portable IC drivers
  directly.
- Protocol and transport code contain no product hardware control.
- Public headers expose opaque handles where internal state would otherwise leak across layers.
- A stateful hardware resource has exactly one writer. Other modules send requests to its owner.
- No application module writes an ESP32 GPIO or a 74HC595 image directly.

## 3. Common status and error model

Portable modules return one status category:

| Status | Meaning | Typical handling |
|---|---|---|
| `OK` | Operation completed | Continue |
| `INVALID_ARGUMENT` | Input is outside the interface contract | Reject request |
| `INVALID_STATE` | Operation is not allowed in the current state | Reject request |
| `NOT_INITIALIZED` | Required initialization has not completed | Stop operation |
| `NOT_FOUND` | Expected device or card is absent | Mark unavailable |
| `BUSY` | Owner is processing an incompatible request | Retry or reject |
| `TIMEOUT` | Required event did not occur before its deadline | Count and recover/stop |
| `IO` | Bus or peripheral operation failed | Add resource context |
| `INTEGRITY` | CRC, header, or framing validation failed | Mark data invalid and count |
| `OVERFLOW` | Queue, pool, or device overrun caused data loss | Preserve a visible gap |
| `UNSUPPORTED` | Feature or configuration is unavailable | Return supported capabilities |
| `HARDWARE_FAULT` | Board or component is unsafe/unusable | Enter the defined safe response |
| `INTERNAL` | Firmware invariant was violated | Report and enter a safe state |

Rules:

- Portable drivers never expose `esp_err_t`.
- Platform adapters translate ESP-IDF results into the common status model and may return an
  optional `fw_error_context_t` containing the normalized status, resource category, operation,
  resource instance, and portable operation-specific detail.
- Passing a null error-context output requests status-only handling. A provided context is cleared
  on success, and its `detail` field never contains a raw ESP-IDF error value.
- Board/card layers preserve useful lower-layer context or replace it with the product resource and
  operation at their own boundary.
- Public protocol errors use stable wire error codes, not ESP-IDF or private driver numbers.
- The per-call error context is internal firmware state and is not serialized directly.
- Repeated errors may be coalesced, but their count is never lost.
- ADC data loss is represented by sequence discontinuity and counters, never only by a text log.

## 4. Platform service contracts

Task-context platform and transport callbacks carry an opaque resource pointer and may accept an
optional error-context output. Unless explicitly named ISR-safe, callbacks are called only from task
context.

### SPI

- Portable drivers use a synchronous full-duplex transfer for register/configuration traffic and
  may additionally use the prepared-burst callbacks for deterministic acquisition traffic.
- `burst_prepare` reserves the bus and immutable repeating TX pattern once; `burst_trigger`
  completes the preceding DMA burst and immediately launches the next into the alternate RX
  buffer; `burst_finish` drains the final burst and releases the session.
- The ESP32-S3 SPI peripheral asserts and releases chip select around every
  transaction. A prepared acquisition session keeps the bus and DMA resources
  reserved, but never holds chip select active between bursts.
- The polling-start/polling-end naming describes the ESP-IDF driver path, not a CPU loop spanning
  the conversion period. DMA clocks each 32-byte frame while the capture task blocks on DRDY.
- The context binds a configured SPI device, including bus, chip select, mode, and clock.
- A transfer is atomic relative to other devices on the same bus.
- The caller supplies transmit and/or receive buffers, byte length, and timeout.
- Null TX produces filler bytes; null RX discards received bytes.
- DMA-safe TX and double RX buffers are allocated before acquisition and never allocated during
  steady state. Completed frames are copied into a fixed 256-entry producer/consumer ring before
  the corresponding DMA buffer is reused.
- The board supplies the initial and maximum clocks, and the platform reports the achieved
  hardware clock. The current diagnostic build uses fixed 20 MHz for both
  register traffic and conversion reads. Fixed 8 MHz, 10 MHz, and 12 MHz missed
  the current 16 kSPS DRDY-to-DMA deadline, while a longer 16 MHz capture lost
  conversions during storage activity. Hardware-framed CS at 20 MHz preserves
  throughput but does not eliminate CRC-marked phase errors, and the clock
  remains above the limit implied by the datasheet's worst-case SDO
  output-valid timing.
- No SPI transfer occurs in a GPIO ISR.
- AD7779 and LSM6DSV clock limits come from `board_config.h`, not from application code.

The GPIO interrupt attach operation installs a handler but leaves the pin interrupt disabled. ADC
DRDY is enabled explicitly only after AD7779 reset, synchronization, SRC update, and filter settling
complete. DRDY edges produced before that point are not sequenced. Once enabled, DAT production is
held until eight consecutive frames pass the ADC data CRC, so interface startup corruption is
excluded without suppressing later integrity faults.

### I²C

- Register read, register write, and combined raw transaction operations are reserved for milestone 2.
- The context binds the controller, address, bus speed, and timeout.
- Automatic retry is disabled in the generic callback; the owning driver decides whether retry is
  safe for a specific operation.

### UART and transport

- UART byte movement belongs to `transport_uart`; protocol parsing belongs to
  `task_communication`.
- Reads and writes may block `task_communication` up to a configured timeout but can never block
  `task_acquisition`.
- Partial reads and writes are normal and are handled by the transport/protocol boundary.
- A read waits for its first byte, then returns the bytes already available without waiting to fill
  the caller's buffer. A write returns the number of bytes accepted by the UART and the caller
  continues from that offset.
- The byte count remains valid when an operation times out, so progress is never ambiguous.
- Baud rate is supplied during initialization and the platform reports the actual applied rate.
  Changing rates requires stopping and reinitializing the transport; live switching is not part of
  milestone 1.
- Debug text is never inserted into the binary protocol stream.
- Milestone-1 target is 921600 baud, subject to the board reliability test.

### Unattended field recording

- The radio-silent field build defaults to 8 kSPS with channels 0–3 enabled,
  x8 gain on channels 0–2, and x1 gain on channel 3; channels 4–7 are disabled.
  It starts an SD recording five seconds after application initialization
  using the first unused `fieldNNN` name.
- A three-second hold of the active-low DevKitC BOOT button calls the same
  recording-controller stop path as the host command. That path stops the ADC,
  drains complete buffered records, syncs storage, and closes the file.
- A physical power cut cannot execute firmware cleanup. The BOOT-button stop
  must complete before battery power is switched off; RESET is not a clean
  recording stop.

### GPIO and interrupts

- Task-context operations configure a pin, set an output, and read an input.
- Only explicitly declared `_isr` operations may be called from an ISR.
- The `ADC_DRDY` ISR captures monotonic time, places it in a fixed ISR-safe timestamp ring, and
  notifies `task_acquisition`.
- The ISR does not perform SPI transfers, allocate memory, take a blocking lock, or log text.
- Timestamp-ring overflow increments an ISR-safe counter that becomes a visible acquisition gap.

### Time

- The application and protocol monotonic-time type is an unsigned 64-bit container for the
  ESP32-S3's 54-bit GPTimer count since platform initialization.
- The GPTimer is crystal-clocked at a nominal 10 MHz, so every count represents one 100 ns unit; no
  timestamp unit conversion is performed by the serializer.
- At 10 MHz the 54-bit hardware counter wraps after approximately 57 years of continuous uptime.
- Monotonic time never moves backward and does not represent UTC.
- The `ADC_DRDY` falling edge is the milestone-1 timestamp reference for an ADC frame.
- Delay operations are for initialization and short hardware sequencing only; application tasks use
  notifications/queues rather than polling delays.
- UTC mapping is a separate milestone-2 service and never changes stored monotonic timestamps.

### CRC

- The ESP32-S3 platform exposes stateless CRC-8 big-endian and CRC-32 little-endian primitives
  without exposing ESP-IDF headers to their callers.
- Both operations accept a raw initial or previously returned remainder and return the raw updated
  remainder without applying a final XOR. The platform wrapper compensates for the complements
  performed internally by the ESP ROM API, so buffers can be processed incrementally.
- `platform_crc8_be()` uses polynomial `0x07` and provides the AD7779 pair-frame CRC calculation.
- `platform_crc32_le()` uses the reflected IEEE polynomial `0x04C11DB7`. Protocol callers use an
  initial remainder of `0xFFFFFFFF` and apply a final XOR of `0xFFFFFFFF` to produce the
  CRC-32/ISO-HDLC value defined by `shared/protocol/protocol.md`.
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

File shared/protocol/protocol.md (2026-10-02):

# Communication Protocol

## Document status

This is the sole protocol-definition document

This document defines the complete wire protocol, including framing, byte order,
CRC, command identifiers, command results, payload layouts, data blocks, command
behavior, and failure visibility.

## Commands rules

Every command has exactly one expected reply type.
Each command sent by the host expect a reply from the device. Some commands from the device can be asynchronous but are used in the special cases of data streaming. This asynchronous command doesn't require replies. Receiving an asynchronous message does not complete the pending command.

Timeouts and retries are handled by the host.

Only one host command may be outstanding at a time. An asynchronous `\DAT` message does not satisfy the outstanding command.

All multi-byte integers are encoded in little-endian byte order, including the CRC-32 field. All reserved and padding bytes must be set to zero.

A request with an invalid CRC-32 is silently discarded by the device. The host detects the discarded request through its timeout.

Read-only commands may be retried after a timeout. Before retrying a state-changing command, the host must query the current device state to determine whether the original command was applied.

The counters start at 0 at power on or reset of the device. Blocks are a 512 byte data structure that have a 28 byte header, 480 byte of samples data and 4 bytes of CRC32. There is a counter for to keep track of the order of sampling. This number is related to acquisition only. This 512 byte block of data is use to store data in RAM, in SD storage and as the framing to send data from the device to a host.

The synchronization value for the standard commands is "\CMD" in ASCII (5C 43 4D 44). The streaming blocks coming from the devices are asynchronous commands from the device and start with the synchronisation word "\DAT" in ASCII (5C 44 41 54). 

The counters can overflow and it's okay, the monotonic timer will never overflow so it can be used to keep track of the data order.
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

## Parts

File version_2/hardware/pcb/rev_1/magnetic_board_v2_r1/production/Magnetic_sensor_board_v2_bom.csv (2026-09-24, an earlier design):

Designator | Footprint | Quantity | Value | LCSC Part #
C1, C6, C8 | 1206 | 3 | 10u | C13585
C10, C11, C12, C14, C20, C22, C23, C27, C29, C35, C37, C38, C42, C44, C50, C52, C53, C57 | 1206 | 18 | 4u7 | C29823
C13, C28, C43 | 0603 | 3 | 10n | C57112
C15, C16, C17, C19, C2, C21, C25, C26, C3, C30, C31, C32, C34, C36, C4, C40, C41, C45, C46, C47, C49, C51, C55, C56, C9 | 0603 | 25 | 100n | C14663
C18, C33, C48 | 1206 | 3 | 47u | C96123
C24, C39, C54, C58, C7 | 0805 | 5 | 220n | C5378
C5 | 0603 | 1 | 1n | C1588
D1 | D_SOD-323 | 1 | 1N4148WS | C2128
Q1, Q2 | SOT-89-3 | 2 | D882 | C9634
Q3 | SOT-89-3 | 1 | B772 | C24278
Q4 | SO-8_3.9x4.9mm_P1.27mm | 1 | DMC3028LSD | C460874
R1, R2, R3, R5 | 0603 | 4 | 1k | C21190
R10, R14, R18 | 0603 | 3 | 300k | C5948140
R11, R15, R19, R8 | 0603 | 4 | 20k | C2076520
R12, R16, R20 | 0805 | 3 | 100M | C169373
R13, R17, R9 | 0603 | 3 | 120 | C860088
R21, R22, R23 | 0603 | 3 | 100k | C860056
R4 | 2512 | 1 | 220 | C4202072
R6, R7 | 0603 | 2 | 20 | C22950
RN1 | R_Array_Convex_2x0603 | 1 | 10k | C2654064
RN10, RN11, RN13, RN2, RN3, RN5, RN6, RN7, RN9 | R_Array_Convex_2x0603 | 9 | 20k | C5553154
RN12, RN14, RN4, RN8 | R_Array_Convex_2x0603 | 4 | 1k | C1731140
U10, U4, U7 | VQFN-16-1EP_3x3mm_P0.5mm_EP1.68x1.68mm | 3 | INA851RGTR | C5371575
U11, U5, U8 | VSSOP-8_3x3mm_P0.65mm | 3 | THP210DGK | C976185
U12, U3, U6, U9 | SOIC-8_3.9x4.9mm_P1.27mm | 4 | OPA2197xD | C139363

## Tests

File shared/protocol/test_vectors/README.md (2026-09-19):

# Protocol Test-Vector Plan

This directory contains byte-exact examples derived from the authoritative
layout in `../protocol.md`. Firmware and host tests consume the same files.

The checked-in vectors currently cover `HELLO`, `DEVICE_INFO`,
`DEVICE_GET_CONFIG`, `DEVICE_SET_CONFIG`, `DEVICE_CONFIG`, CRC-invalid
`HELLO`, the temporary `TEMP_RECORDING_READ` request/reply, and one complete
eight-channel `\DAT` block. Additional command and data-block vectors remain
planned below.

Structure:

```text
test_vectors/
├── command/
│   ├── valid/
│   └── invalid/
├── data_block/
│   ├── valid/
│   └── invalid/
└── manifest.json
```

Each manifest entry will identify the command or data-block type, decoded
fields, expected validation result, and purpose. It will not define values that
are absent from `protocol.md`.

The complete command-vector set will cover:

- Every request and named reply currently defined in `protocol.md`.
- Empty and populated 48-byte payload areas.
- Canonical zero padding and little-endian multi-byte fields.
- Invalid `\CMD` magic, direction, payload length, reserved bytes, padding, and
  CRC-32/ISO-HDLC.
- The standard CRC check value `CRC("123456789") = 0xCBF43926`.

The first data-block vector set will cover:

- Eight-channel blocks containing 20 conversions.
- Four-channel blocks containing 40 conversions for masks `0x0F` and `0xF0`.
- Every defined data-block status value.
- Zero, positive, negative, minimum, and maximum signed 24-bit samples.
- Conversion-major ordering and least-significant-byte-first sample packing.
- Payload number, source-conversion sequence, 100 ns timestamp, and 100 ns
  sample-period fields.
- Decimated blocks whose source sequence and stored sample period remain
  coherent.
- Invalid `\DAT` magic, channel mask, status, and CRC-32/ISO-HDLC.

No partial 512-byte data block is valid. Transport tests may split a valid
64-byte command or 512-byte data block across arbitrary reads and must
reassemble it before validation. A host-side mixed-stream test must also verify
that asynchronous `\DAT` blocks do not complete the one outstanding command.

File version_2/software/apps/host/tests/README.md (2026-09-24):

# Host Tests

The tests cover shared golden vectors, arbitrary serial-read fragmentation,
concatenated records, corrupt candidates, boot garbage, exact named-reply
matching with interleaved asynchronous `\DAT` blocks, continuity counters,
byte-exact ADC capture, desktop-worker recording catalog retrieval, and
stream-start sequencing. BLE tests cover fragmented command writes and
fragmented `DEVICE_INFO` notifications without requiring a Bluetooth adapter.

They use Python's standard `unittest` framework and do not require hardware.

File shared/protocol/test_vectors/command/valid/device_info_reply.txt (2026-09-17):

5c434d44a100010000000010000200001234560200010004030201010000000000000000000000000000000000000000000000000000000000000000f0346249

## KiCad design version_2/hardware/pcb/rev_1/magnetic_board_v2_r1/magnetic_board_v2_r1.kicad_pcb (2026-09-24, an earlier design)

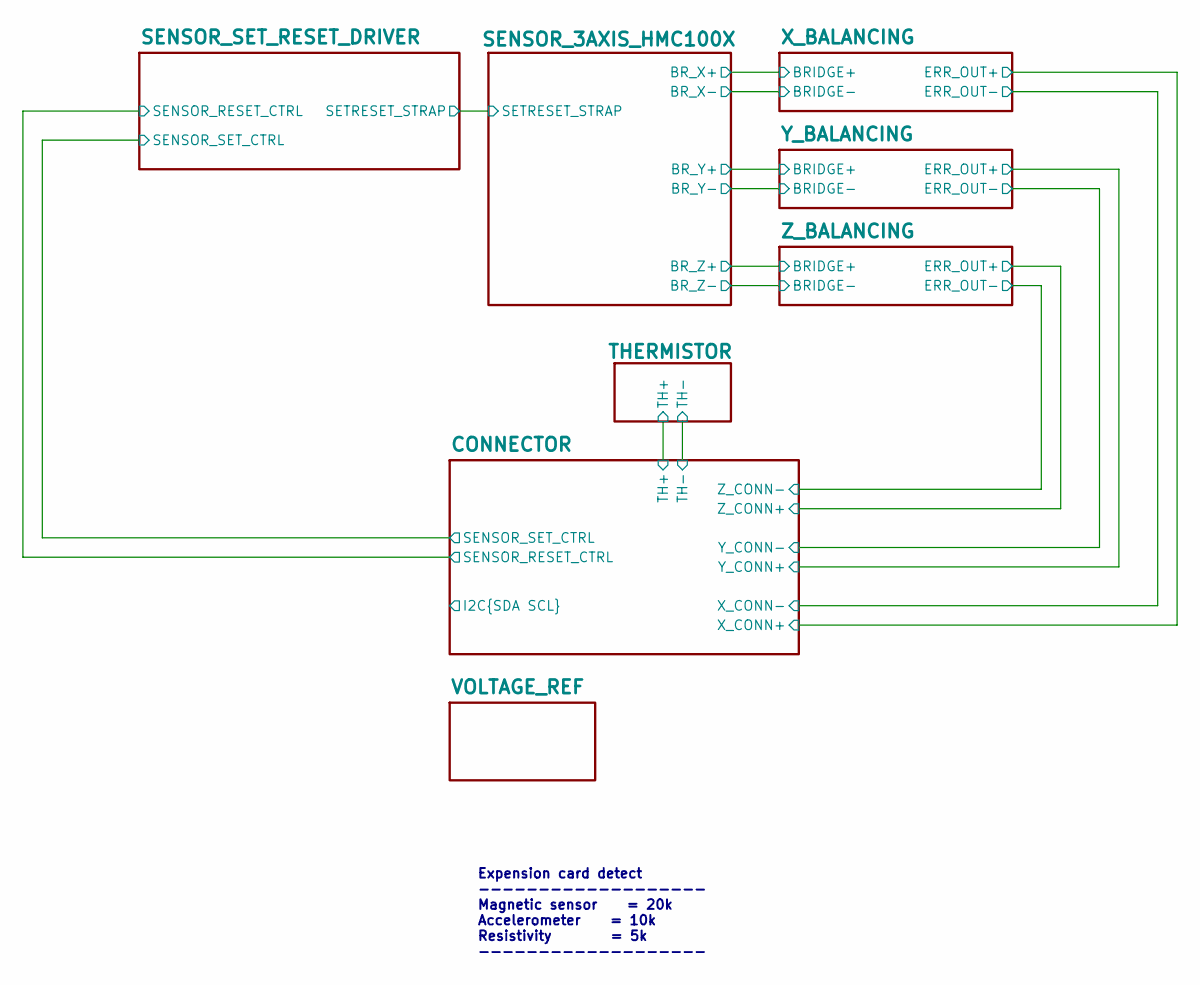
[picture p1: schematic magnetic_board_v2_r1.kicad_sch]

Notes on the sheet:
Expension card detect ------------------- Magnetic sensor = 20k Accelerometer = 10k Resistivity = 5k -------------------

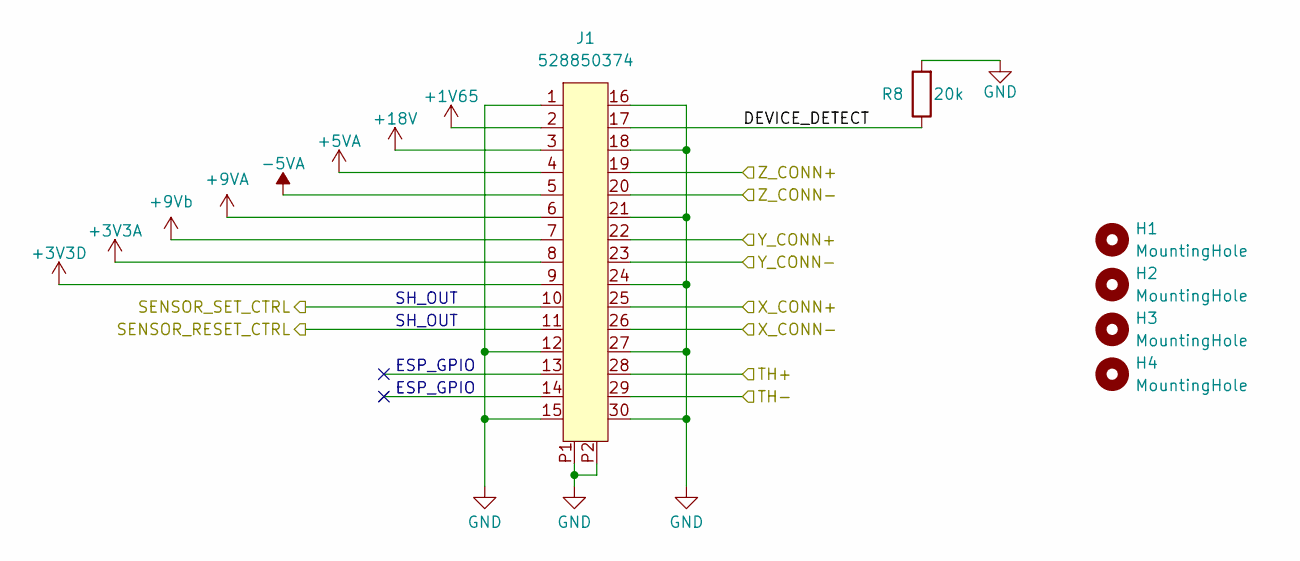
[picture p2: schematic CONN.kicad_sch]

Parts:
H1, H2, H3, H4: MountingHole; MountingHole_4.3mm_M4
J1: 528850374; CON_528850374_MOL
R8: 20k; R_0603_1608Metric; LCSC C2076520

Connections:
+1V65: J1.2; also elsewhere on the board
+3V3A: J1.8; also elsewhere on the board
+3V3D: J1.9
+5VA: J1.4
+9VA: J1.6; also elsewhere on the board
+9Vb: J1.7; also elsewhere on the board
+18V: J1.3; also elsewhere on the board
-5VA: J1.5
/CONNECTOR/DEVICE_DETECT: J1.17, R8.1
/CONNECTOR/SENSOR_RESET_CTRL: J1.11; also elsewhere on the board
/CONNECTOR/SENSOR_SET_CTRL: J1.10; also elsewhere on the board
/CONNECTOR/TH+: J1.28; also elsewhere on the board
/CONNECTOR/TH-: J1.29; also elsewhere on the board
/CONNECTOR/X_CONN+: J1.25; also elsewhere on the board
/CONNECTOR/X_CONN-: J1.26; also elsewhere on the board
/CONNECTOR/Y_CONN+: J1.22; also elsewhere on the board
/CONNECTOR/Y_CONN-: J1.23; also elsewhere on the board
/CONNECTOR/Z_CONN+: J1.19; also elsewhere on the board
/CONNECTOR/Z_CONN-: J1.20; also elsewhere on the board
GND: J1.1, J1.12, J1.15, J1.16, J1.18, J1.21, J1.24, J1.27, J1.30, J1.P1, J1.P2, R8.2; also elsewhere on the board

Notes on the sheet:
ESP_GPIO
SH_OUT

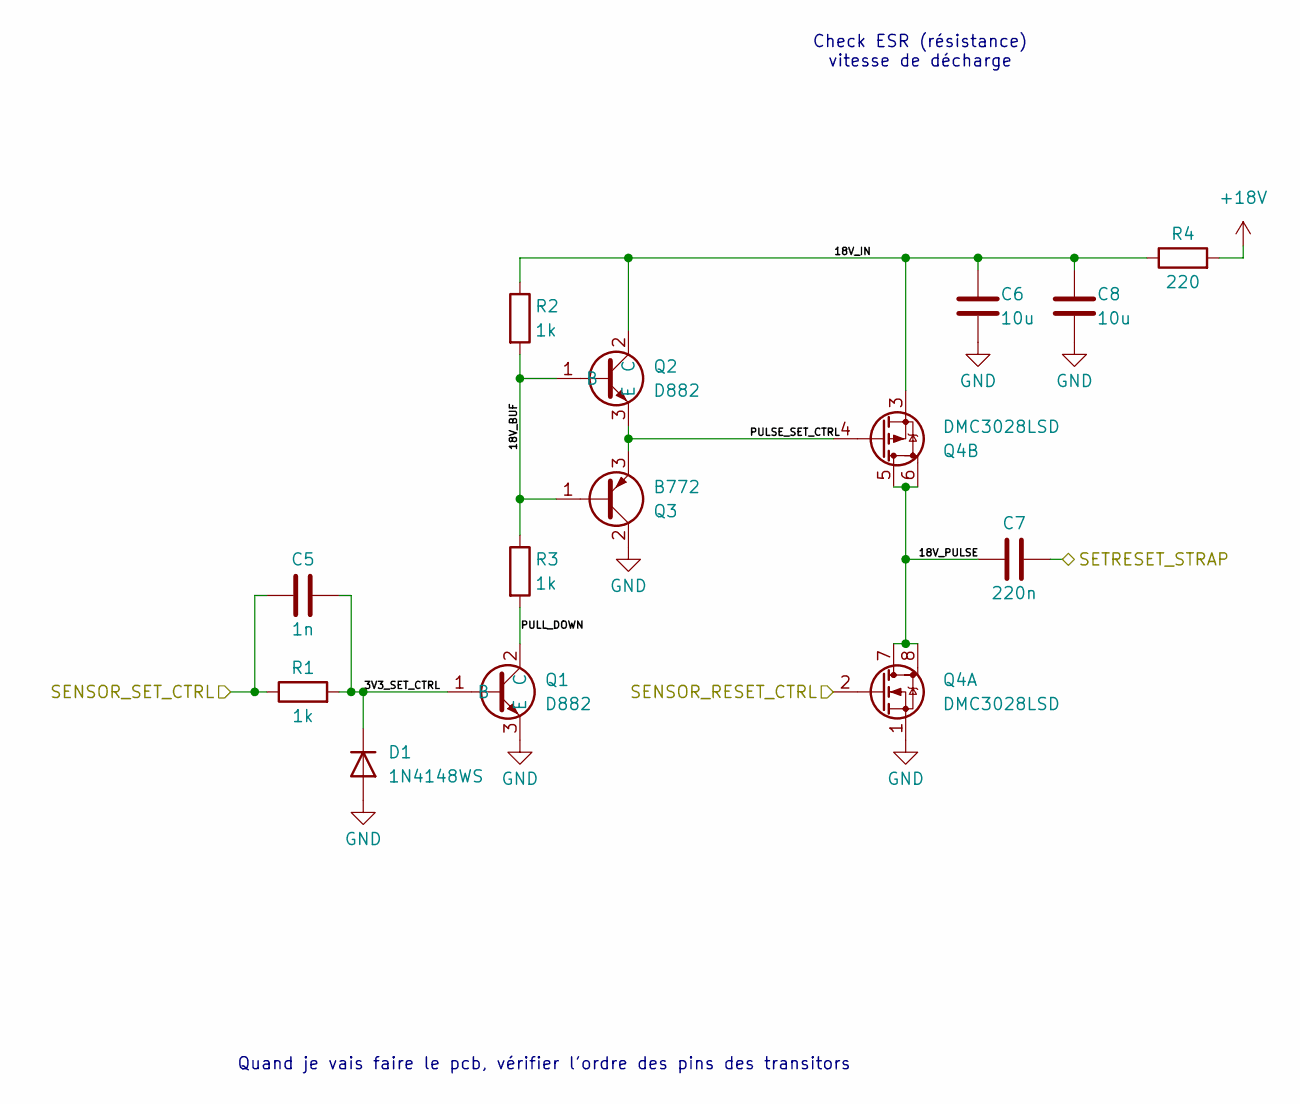
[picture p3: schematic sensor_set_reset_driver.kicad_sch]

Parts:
C5: 1n; C_0603_1608Metric; LCSC C1588
C6, C8: 10u; C_1206_3216Metric; LCSC C13585
C7: 220n; C_0805_2012Metric; LCSC C5378
D1: 1N4148WS; D_SOD-323; LCSC C2128
Q1, Q2: D882; SOT-89-3; LCSC C9634
Q3: B772; SOT-89-3; LCSC C24278
Q4: DMC3028LSD; SO-8_3.9x4.9mm_P1.27mm; LCSC C460874
R1, R2, R3: 1k; R_0603_1608Metric; LCSC C21190
R4: 220; R_2512_6332Metric; LCSC C4202072

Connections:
+18V: R4.2; also elsewhere on the board
/CONNECTOR/SENSOR_RESET_CTRL: Q4.2 (G1); also elsewhere on the board
/CONNECTOR/SENSOR_SET_CTRL: C5.1, R1.1; also elsewhere on the board
/SENSOR_3AXIS_HMC100X/SETRESET_STRAP: C7.2; also elsewhere on the board
/SENSOR_SET_RESET_DRIVER/3V3_SET_CTRL: C5.2, D1.1 (K), Q1.1 (B), R1.2
/SENSOR_SET_RESET_DRIVER/18V_BUF: Q2.1 (B), Q3.1, R2.2, R3.1
/SENSOR_SET_RESET_DRIVER/18V_IN: C6.1, C8.1, Q2.2 (C), Q4.3 (S2), R2.1, R4.1
/SENSOR_SET_RESET_DRIVER/18V_PULSE: C7.1, Q4.5 (D2), Q4.6 (D2), Q4.7 (D1), Q4.8 (D1)
/SENSOR_SET_RESET_DRIVER/PULL_DOWN: Q1.2 (C), R3.2
/SENSOR_SET_RESET_DRIVER/PULSE_SET_CTRL: Q2.3 (E), Q3.3, Q4.4 (G2)
GND: C6.2, C8.2, D1.2 (A), Q1.3 (E), Q3.2, Q4.1 (S1); also elsewhere on the board

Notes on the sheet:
Check ESR (résistance) vitesse de décharge
Quand je vais faire le pcb, vérifier l'ordre des pins des transitors

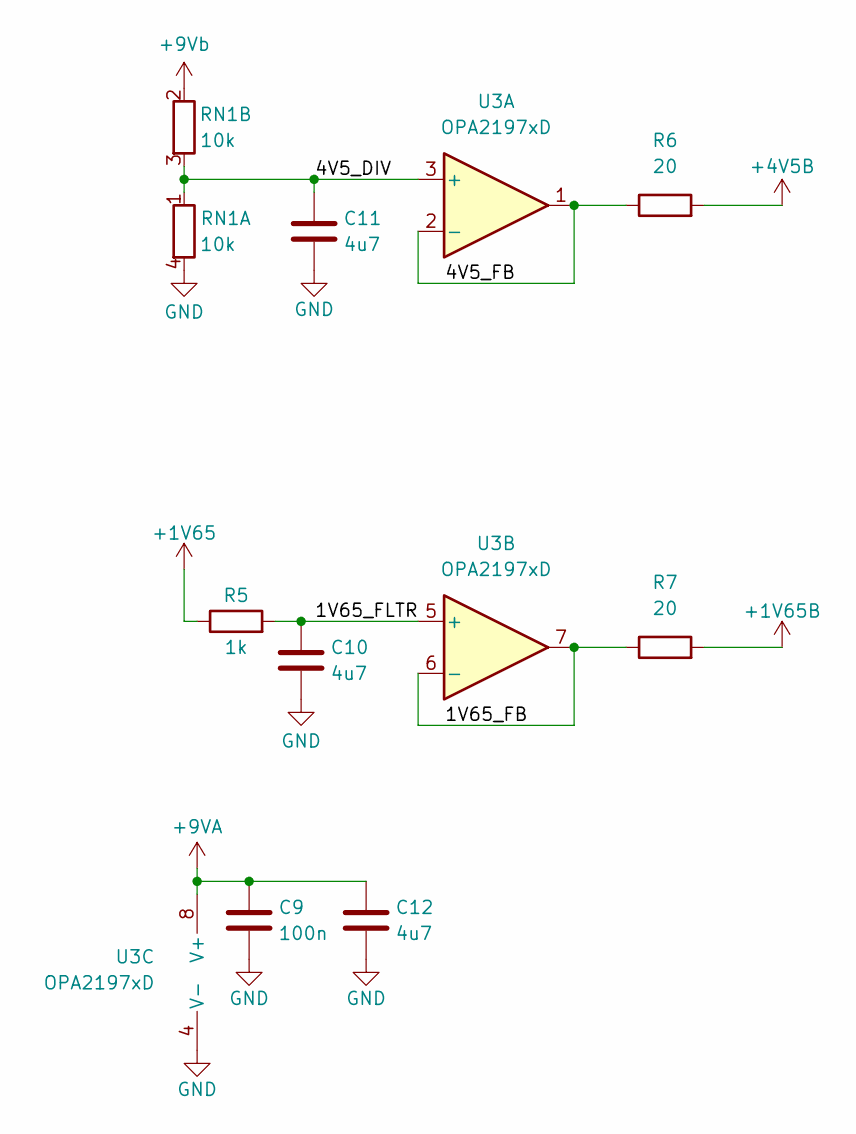
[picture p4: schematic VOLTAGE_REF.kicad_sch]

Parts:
C9: 100n; C_0603_1608Metric; LCSC C14663
C10, C11, C12: 4u7; C_1206_3216Metric; LCSC C29823
R5: 1k; R_0603_1608Metric; LCSC C21190
R6, R7: 20; R_0603_1608Metric; LCSC C22950
RN1: 10k; R_Array_Convex_2x0603; LCSC C2654064
U3: OPA2197xD; SOIC-8_3.9x4.9mm_P1.27mm; LCSC C139363

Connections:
+1V65: R5.1; also elsewhere on the board
+1V65B: R7.2; also elsewhere on the board
+4V5B: R6.2; also elsewhere on the board
+9VA: C9.1, C12.1, U3.8 (V+); also elsewhere on the board
+9Vb: RN1.2 (R2.1); also elsewhere on the board
/VOLTAGE_REF/1V65_FB: R7.1, U3.6 (-), U3.7
/VOLTAGE_REF/1V65_FLTR: C10.1, R5.2, U3.5 (+)
/VOLTAGE_REF/4V5_DIV: C11.1, RN1.1 (R1.1), RN1.3 (R2.2), U3.3 (+)
/VOLTAGE_REF/4V5_FB: R6.1, U3.1, U3.2 (-)
GND: C9.2, C10.2, C11.2, C12.2, RN1.4 (R1.2), U3.4 (V-); also elsewhere on the board

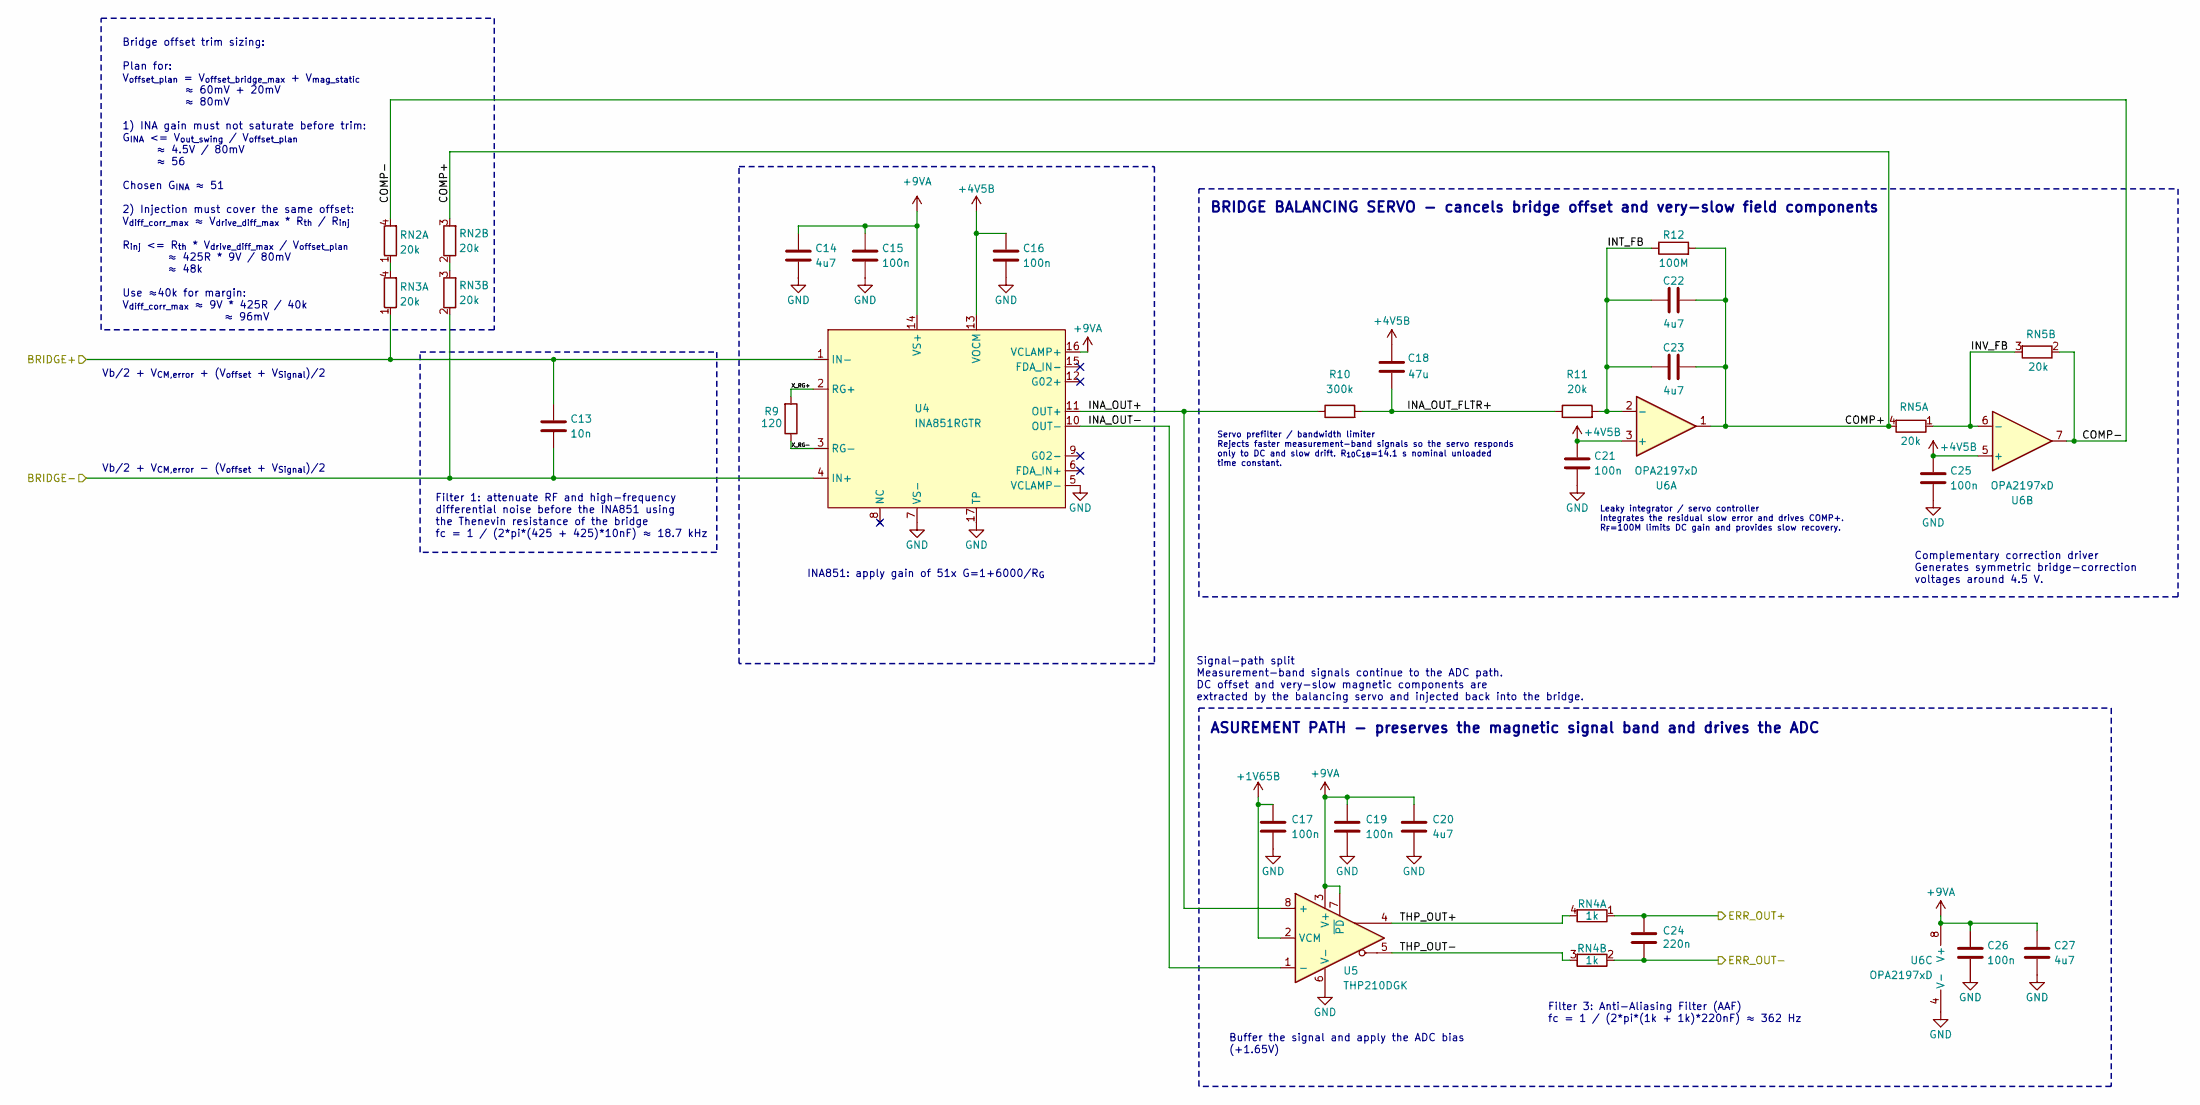
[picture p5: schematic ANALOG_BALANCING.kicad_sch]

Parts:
C13: 10n; C_0603_1608Metric; LCSC C57112
C14, C20, C22, C23, C27: 4u7; C_1206_3216Metric; LCSC C29823
C15, C16, C17, C19, C21, C25, C26: 100n; C_0603_1608Metric; LCSC C14663
C18: 47u; C_1206_3216Metric; LCSC C96123
C24: 220n; C_0805_2012Metric; LCSC C5378
R9: 120; R_0603_1608Metric; LCSC C860088
R10: 300k; R_0603_1608Metric; LCSC C5948140
R11: 20k; R_0603_1608Metric; LCSC C2076520
R12: 100M; R_0805_2012Metric; LCSC C169373
RN2, RN3, RN5: 20k; R_Array_Convex_2x0603; LCSC C5553154
RN4: 1k; R_Array_Convex_2x0603; LCSC C1731140
U4: INA851RGTR; VQFN-16-1EP_3x3mm_P0.5mm_EP1.68x1.68mm; LCSC C5371575
U5: THP210DGK; VSSOP-8_3x3mm_P0.65mm; LCSC C976185
U6: OPA2197xD; SOIC-8_3.9x4.9mm_P1.27mm; LCSC C139363

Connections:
+1V65B: C17.1, U5.2 (VCM); also elsewhere on the board
+4V5B: C16.1, C18.2, C21.1, C25.1, U4.13 (VOCM), U6.3 (+), U6.5 (+); also elsewhere on the board
+9VA: C14.1, C15.1, C19.1, C20.1, C26.1, C27.1, U4.14 (VS+), U4.16 (VCLAMP+), U5.3 (V+), U5.7 (~PD), U6.8 (V+); also elsewhere on the board
/CONNECTOR/X_CONN+: C24.2, RN4.1 (R1.1); also elsewhere on the board
/CONNECTOR/X_CONN-: C24.1, RN4.2 (R2.1); also elsewhere on the board
/SENSOR_3AXIS_HMC100X/BR_X+: C13.1, RN3.1 (R1.1), U4.1 (IN-); also elsewhere on the board
/SENSOR_3AXIS_HMC100X/BR_X-: C13.2, RN3.2 (R2.1), U4.4 (IN+); also elsewhere on the board
/X_BALANCING/COMP+: C22.2, C23.2, R12.2, RN2.3 (R2.2), RN5.4 (R1.2), U6.1
/X_BALANCING/COMP-: RN2.4 (R1.2), RN5.2 (R2.1), U6.7
/X_BALANCING/INA_OUT+: R10.1, U4.11 (OUT+), U5.8 (+)
/X_BALANCING/INA_OUT-: U4.10 (OUT-), U5.1 (-)
/X_BALANCING/INA_OUT_FLTR+: C18.1, R10.2, R11.1
/X_BALANCING/INT_FB: C22.1, C23.1, R11.2, R12.1, U6.2 (-)
/X_BALANCING/INV_FB: RN5.1 (R1.1), RN5.3 (R2.2), U6.6 (-)
/X_BALANCING/THP_OUT+: RN4.4 (R1.2), U5.4
/X_BALANCING/THP_OUT-: RN4.3 (R2.2), U5.5
/X_BALANCING/X_RG+: R9.2, U4.2 (RG+)
/X_BALANCING/X_RG-: R9.1, U4.3 (RG-)
GND: C14.2, C15.2, C16.2, C17.2, C19.2, C20.2, C21.2, C25.2, C26.2, C27.2, U4.5 (VCLAMP-), U4.7 (VS-), U4.17 (TP), U5.6 (V-), U6.4 (V-); also elsewhere on the board
unnamed: RN2.1 (R1.1), RN3.4 (R1.2)
unnamed: RN2.2 (R2.1), RN3.3 (R2.2)

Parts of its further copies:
C28, C43: 10n; C_0603_1608Metric; LCSC C57112
C29, C35, C37, C38, C42, C44, C50, C52, C53, C57: 4u7; C_1206_3216Metric; LCSC C29823
C30, C31, C32, C34, C36, C40, C41, C45, C46, C47, C49, C51, C55, C56: 100n; C_0603_1608Metric; LCSC C14663
C33, C48: 47u; C_1206_3216Metric; LCSC C96123
C39, C54: 220n; C_0805_2012Metric; LCSC C5378
R13, R17: 120; R_0603_1608Metric; LCSC C860088
R14, R18: 300k; R_0603_1608Metric; LCSC C5948140
R15, R19: 20k; R_0603_1608Metric; LCSC C2076520
R16, R20: 100M; R_0805_2012Metric; LCSC C169373
RN6, RN7, RN9, RN10, RN11, RN13: 20k; R_Array_Convex_2x0603; LCSC C5553154
RN8, RN12: 1k; R_Array_Convex_2x0603; LCSC C1731140
U7, U10: INA851RGTR; VQFN-16-1EP_3x3mm_P0.5mm_EP1.68x1.68mm; LCSC C5371575
U8, U11: THP210DGK; VSSOP-8_3x3mm_P0.65mm; LCSC C976185
U9, U12: OPA2197xD; SOIC-8_3.9x4.9mm_P1.27mm; LCSC C139363

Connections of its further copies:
+1V65B: C32.1, C47.1, U8.2 (VCM), U11.2 (VCM); also elsewhere on the board
+4V5B: C31.1, C33.2, C36.1, C40.1, C46.1, C48.2, C51.1, C55.1, U7.13 (VOCM), U9.3 (+), U9.5 (+), U10.13 (VOCM), U12.3 (+), U12.5 (+); also elsewhere on the board
+9VA: C29.1, C30.1, C34.1, C35.1, C41.1, C42.1, C44.1, C45.1, C49.1, C50.1, C56.1, C57.1, U7.14 (VS+), U7.16 (VCLAMP+), U8.3 (V+), U8.7 (~PD), U9.8 (V+), U10.14 (VS+), U10.16 (VCLAMP+), U11.3 (V+), U11.7 (~PD), U12.8 (V+); also elsewhere on the board
/CONNECTOR/Y_CONN+: C39.2, RN8.1 (R1.1); also elsewhere on the board
/CONNECTOR/Y_CONN-: C39.1, RN8.2 (R2.1); also elsewhere on the board
/CONNECTOR/Z_CONN+: C54.2, RN12.1 (R1.1); also elsewhere on the board
/CONNECTOR/Z_CONN-: C54.1, RN12.2 (R2.1); also elsewhere on the board
/SENSOR_3AXIS_HMC100X/BR_Y+: C28.1, RN7.1 (R1.1), U7.1 (IN-); also elsewhere on the board
/SENSOR_3AXIS_HMC100X/BR_Y-: C28.2, RN7.2 (R2.1), U7.4 (IN+); also elsewhere on the board
/SENSOR_3AXIS_HMC100X/BR_Z+: C43.1, RN11.1 (R1.1), U10.1 (IN-); also elsewhere on the board
/SENSOR_3AXIS_HMC100X/BR_Z-: C43.2, RN11.2 (R2.1), U10.4 (IN+); also elsewhere on the board
/Y_BALANCING/COMP+: C37.2, C38.2, R16.2, RN6.3 (R2.2), RN9.4 (R1.2), U9.1
/Y_BALANCING/COMP-: RN6.4 (R1.2), RN9.2 (R2.1), U9.7
/Y_BALANCING/INA_OUT+: R14.1, U7.11 (OUT+), U8.8 (+)
/Y_BALANCING/INA_OUT-: U7.10 (OUT-), U8.1 (-)
/Y_BALANCING/INA_OUT_FLTR+: C33.1, R14.2, R15.1
/Y_BALANCING/INT_FB: C37.1, C38.1, R15.2, R16.1, U9.2 (-)
/Y_BALANCING/INV_FB: RN9.1 (R1.1), RN9.3 (R2.2), U9.6 (-)
/Y_BALANCING/THP_OUT+: RN8.4 (R1.2), U8.4
/Y_BALANCING/THP_OUT-: RN8.3 (R2.2), U8.5
/Y_BALANCING/X_RG+: R13.2, U7.2 (RG+)
/Y_BALANCING/X_RG-: R13.1, U7.3 (RG-)
/Z_BALANCING/COMP+: C52.2, C53.2, R20.2, RN10.3 (R2.2), RN13.4 (R1.2), U12.1
/Z_BALANCING/COMP-: RN10.4 (R1.2), RN13.2 (R2.1), U12.7
/Z_BALANCING/INA_OUT+: R18.1, U10.11 (OUT+), U11.8 (+)
/Z_BALANCING/INA_OUT-: U10.10 (OUT-), U11.1 (-)
/Z_BALANCING/INA_OUT_FLTR+: C48.1, R18.2, R19.1
/Z_BALANCING/INT_FB: C52.1, C53.1, R19.2, R20.1, U12.2 (-)
/Z_BALANCING/INV_FB: RN13.1 (R1.1), RN13.3 (R2.2), U12.6 (-)
/Z_BALANCING/THP_OUT+: RN12.4 (R1.2), U11.4
/Z_BALANCING/THP_OUT-: RN12.3 (R2.2), U11.5
/Z_BALANCING/X_RG+: R17.2, U10.2 (RG+)
/Z_BALANCING/X_RG-: R17.1, U10.3 (RG-)
GND: C29.2, C30.2, C31.2, C32.2, C34.2, C35.2, C36.2, C40.2, C41.2, C42.2, C44.2, C45.2, C46.2, C47.2, C49.2, C50.2, C51.2, C55.2, C56.2, C57.2, U7.5 (VCLAMP-), U7.7 (VS-), U7.17 (TP), U8.6 (V-), U9.4 (V-), U10.5 (VCLAMP-), U10.7 (VS-), U10.17 (TP), U11.6 (V-), U12.4 (V-); also elsewhere on the board
unnamed: RN6.1 (R1.1), RN7.4 (R1.2)
unnamed: RN6.2 (R2.1), RN7.3 (R2.2)
unnamed: RN10.1 (R1.1), RN11.4 (R1.2)
unnamed: RN10.2 (R2.1), RN11.3 (R2.2)

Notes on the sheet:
BRIDGE BALANCING SERVO - cancels bridge offset and very-slow field components
Filter 1: attenuate RF and high-frequency differential noise before the INA851 using the Thenevin resistance of the bridge fc = 1 / (2*pi*(425 + 425)*10nF) ≈ 18.7 kHz
Servo prefilter / bandwidth limiter Rejects faster measurement-band signals so the servo responds only to DC and slow drift. R_{10}C_{18}=14.1 s nominal unloaded time constant.
Buffer the signal and apply the ADC bias (+1.65V)
Vb/2 + V_{CM,error} + (V_{offset} + V_{Signal})/2
Leaky integrator / servo controller Integrates the residual slow error and drives COMP+. R_{F}=100M limits DC gain and provides slow recovery.
Complementary correction driver Generates symmetric bridge-correction voltages around 4.5 V.
Vb/2 + V_{CM,error} - (V_{offset} + V_{Signal})/2
ASUREMENT PATH - preserves the magnetic signal band and drives the ADC
Bridge offset trim sizing: Plan for: V_{offset_plan} = V_{offset_bridge_max} + V_{mag_static} ≈ 60mV + 20mV ≈ 80mV 1) INA gain must not saturate before trim: G_{INA} <= V_{out_swing} / V_{offset_plan} ≈ 4.5V / 80mV ≈ 56 Chosen G_{INA} ≈ 51 2) Injection must cover the same offset: V_{diff_corr_max} 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
INA851: apply gain of 51x G=1+6000/R_{G}
Signal-path split Measurement-band signals continue to the ADC path. DC offset and very-slow magnetic components are extracted by the balancing servo and injected back into the bridge.
Filter 3: Anti-Aliasing Filter (AAF) fc = 1 / (2*pi*(1k + 1k)*220nF) ≈ 362 Hz

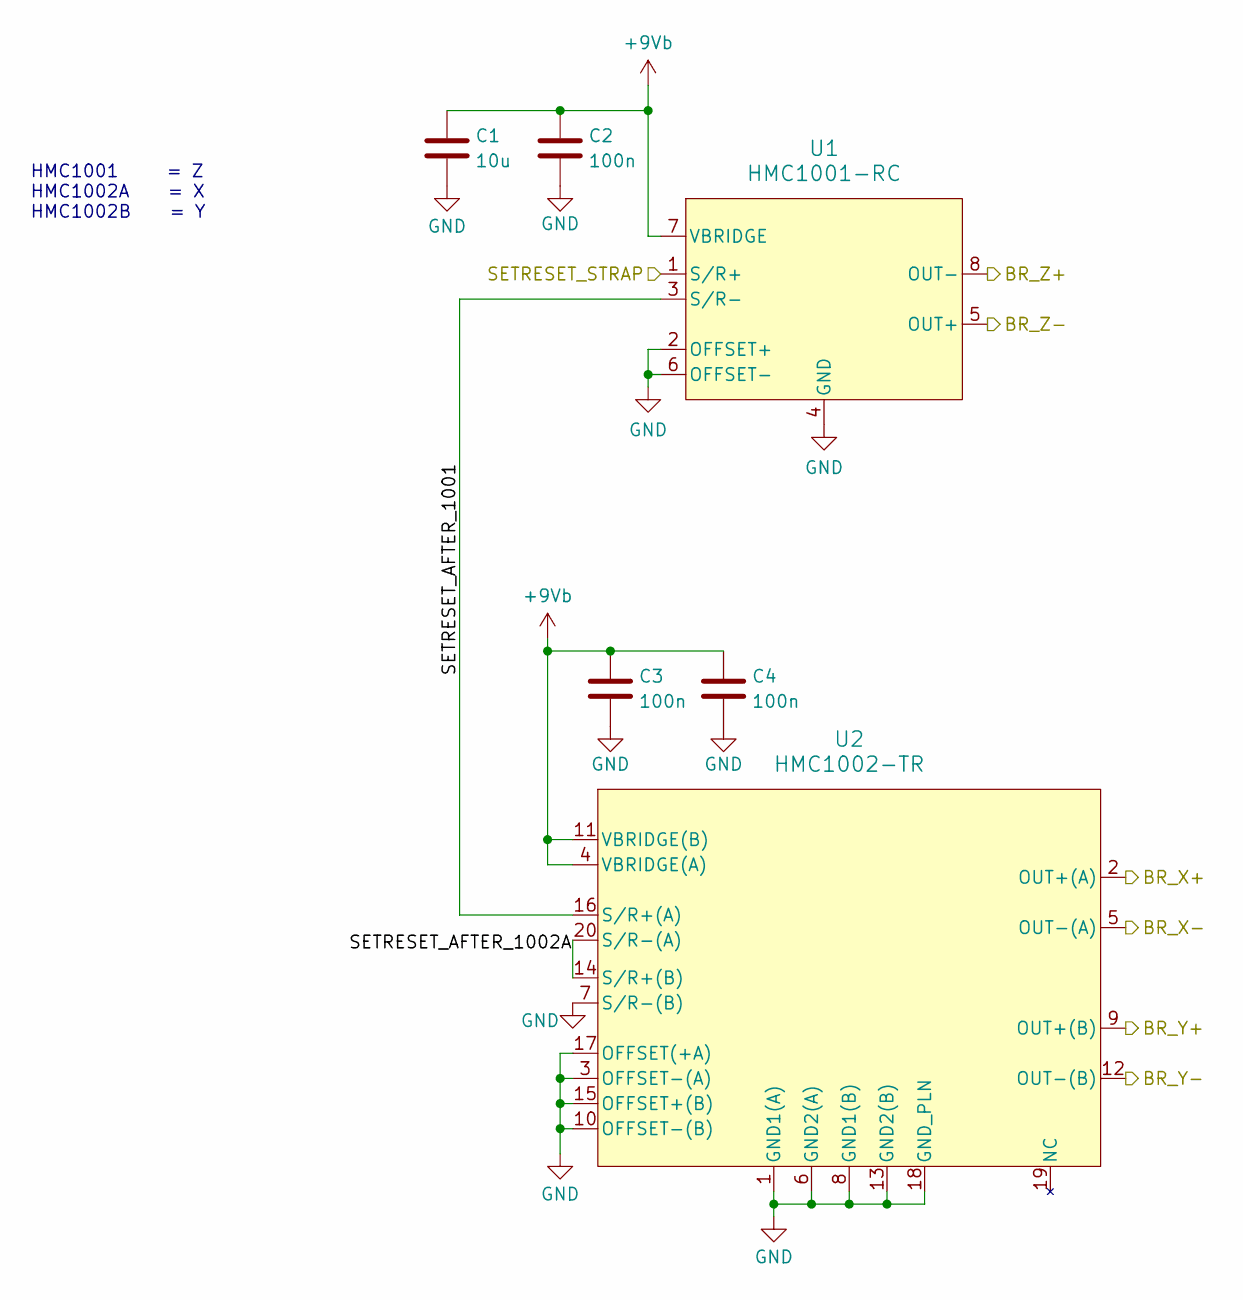
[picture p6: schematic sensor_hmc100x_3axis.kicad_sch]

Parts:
C1: 10u; C_1206_3216Metric; LCSC C13585
C2, C3, C4: 100n; C_0603_1608Metric; LCSC C14663
U1: HMC1001-RC; SIP8_HMC1001_HNW
U2: HMC1002-TR; SOIC20_HNW

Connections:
+9Vb: C1.1, C2.1, C3.1, C4.1, U1.7 (VBRIDGE), U2.4 (VBRIDGE(A)), U2.11 (VBRIDGE(B)); also elsewhere on the board
/SENSOR_3AXIS_HMC100X/BR_X+: U2.2 (OUT+(A)); also elsewhere on the board
/SENSOR_3AXIS_HMC100X/BR_X-: U2.5 (OUT-(A)); also elsewhere on the board
/SENSOR_3AXIS_HMC100X/BR_Y+: U2.9 (OUT+(B)); also elsewhere on the board
/SENSOR_3AXIS_HMC100X/BR_Y-: U2.12 (OUT-(B)); also elsewhere on the board
/SENSOR_3AXIS_HMC100X/BR_Z+: U1.8 (OUT-); also elsewhere on the board
/SENSOR_3AXIS_HMC100X/BR_Z-: U1.5 (OUT+); also elsewhere on the board
/SENSOR_3AXIS_HMC100X/SETRESET_AFTER_1001: U1.3 (S/R-), U2.16 (S/R+(A))
/SENSOR_3AXIS_HMC100X/SETRESET_AFTER_1002A: U2.14 (S/R+(B)), U2.20 (S/R-(A))
/SENSOR_3AXIS_HMC100X/SETRESET_STRAP: U1.1 (S/R+); also elsewhere on the board
GND: C1.2, C2.2, C3.2, C4.2, U1.2 (OFFSET+), U1.4 (GND), U1.6 (OFFSET-), U2.1 (GND1(A)), U2.3 (OFFSET-(A)), U2.6 (GND2(A)), U2.7 (S/R-(B)), U2.8 (GND1(B)), U2.10 (OFFSET-(B)), U2.13 (GND2(B)), U2.15 (OFFSET+(B)), U2.17 (OFFSET(+A)), U2.18 (GND_PLN); also elsewhere on the board

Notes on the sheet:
HMC1001 = Z HMC1002A = X HMC1002B = Y

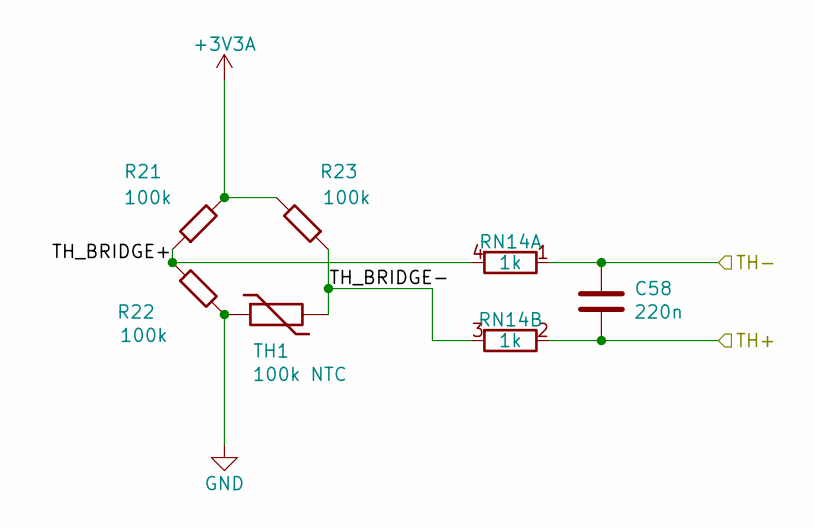
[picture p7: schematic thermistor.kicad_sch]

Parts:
C58: 220n; C_0805_2012Metric; LCSC C5378
R21, R22, R23: 100k; R_0603_1608Metric; LCSC C860056
RN14: 1k; R_Array_Convex_2x0603; LCSC C1731140
TH1: 100k NTC; R_0603_1608Metric; LCSC C3154303

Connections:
+3V3A: R21.2, R23.2; also elsewhere on the board
/CONNECTOR/TH+: C58.1, RN14.2 (R2.1); also elsewhere on the board
/CONNECTOR/TH-: C58.2, RN14.1 (R1.1); also elsewhere on the board
/THERMISTOR/TH_BRIDGE+: R21.1, R22.1, RN14.4 (R1.2)
/THERMISTOR/TH_BRIDGE-: R23.1, RN14.3 (R2.2), TH1.2
GND: R22.2, TH1.1; also elsewhere on the board

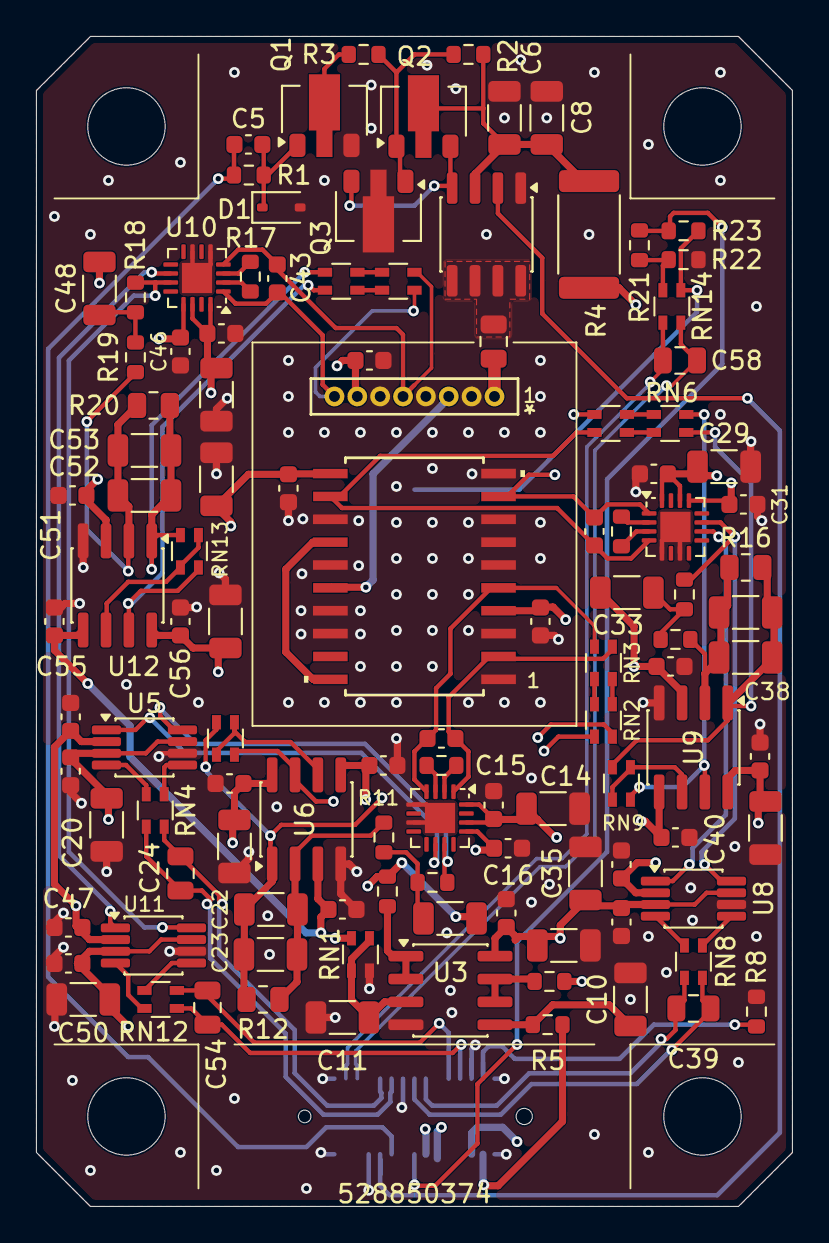
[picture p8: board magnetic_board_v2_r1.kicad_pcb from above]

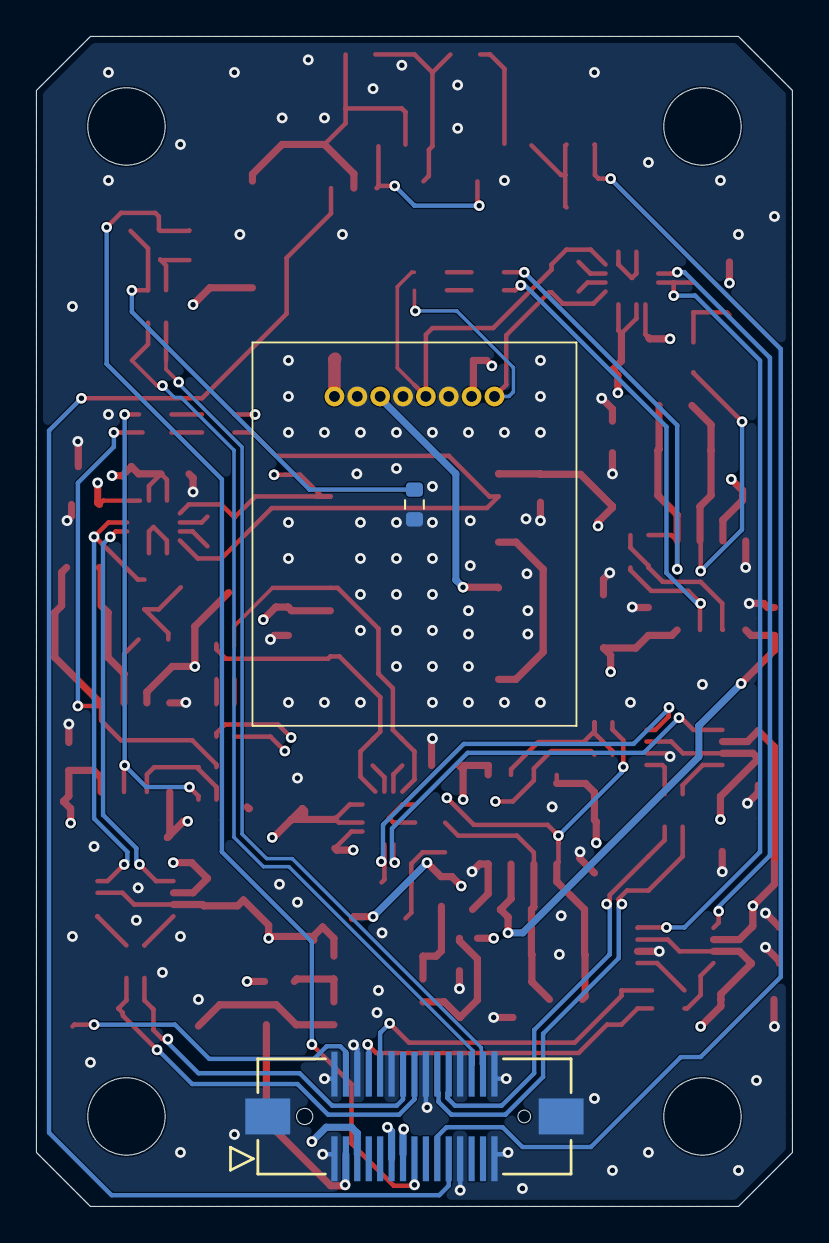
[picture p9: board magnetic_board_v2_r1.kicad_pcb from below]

Board: 4 copper layers, 42.0 x 65.0 mm, 118 parts (2 on the bottom side), 79 nets.

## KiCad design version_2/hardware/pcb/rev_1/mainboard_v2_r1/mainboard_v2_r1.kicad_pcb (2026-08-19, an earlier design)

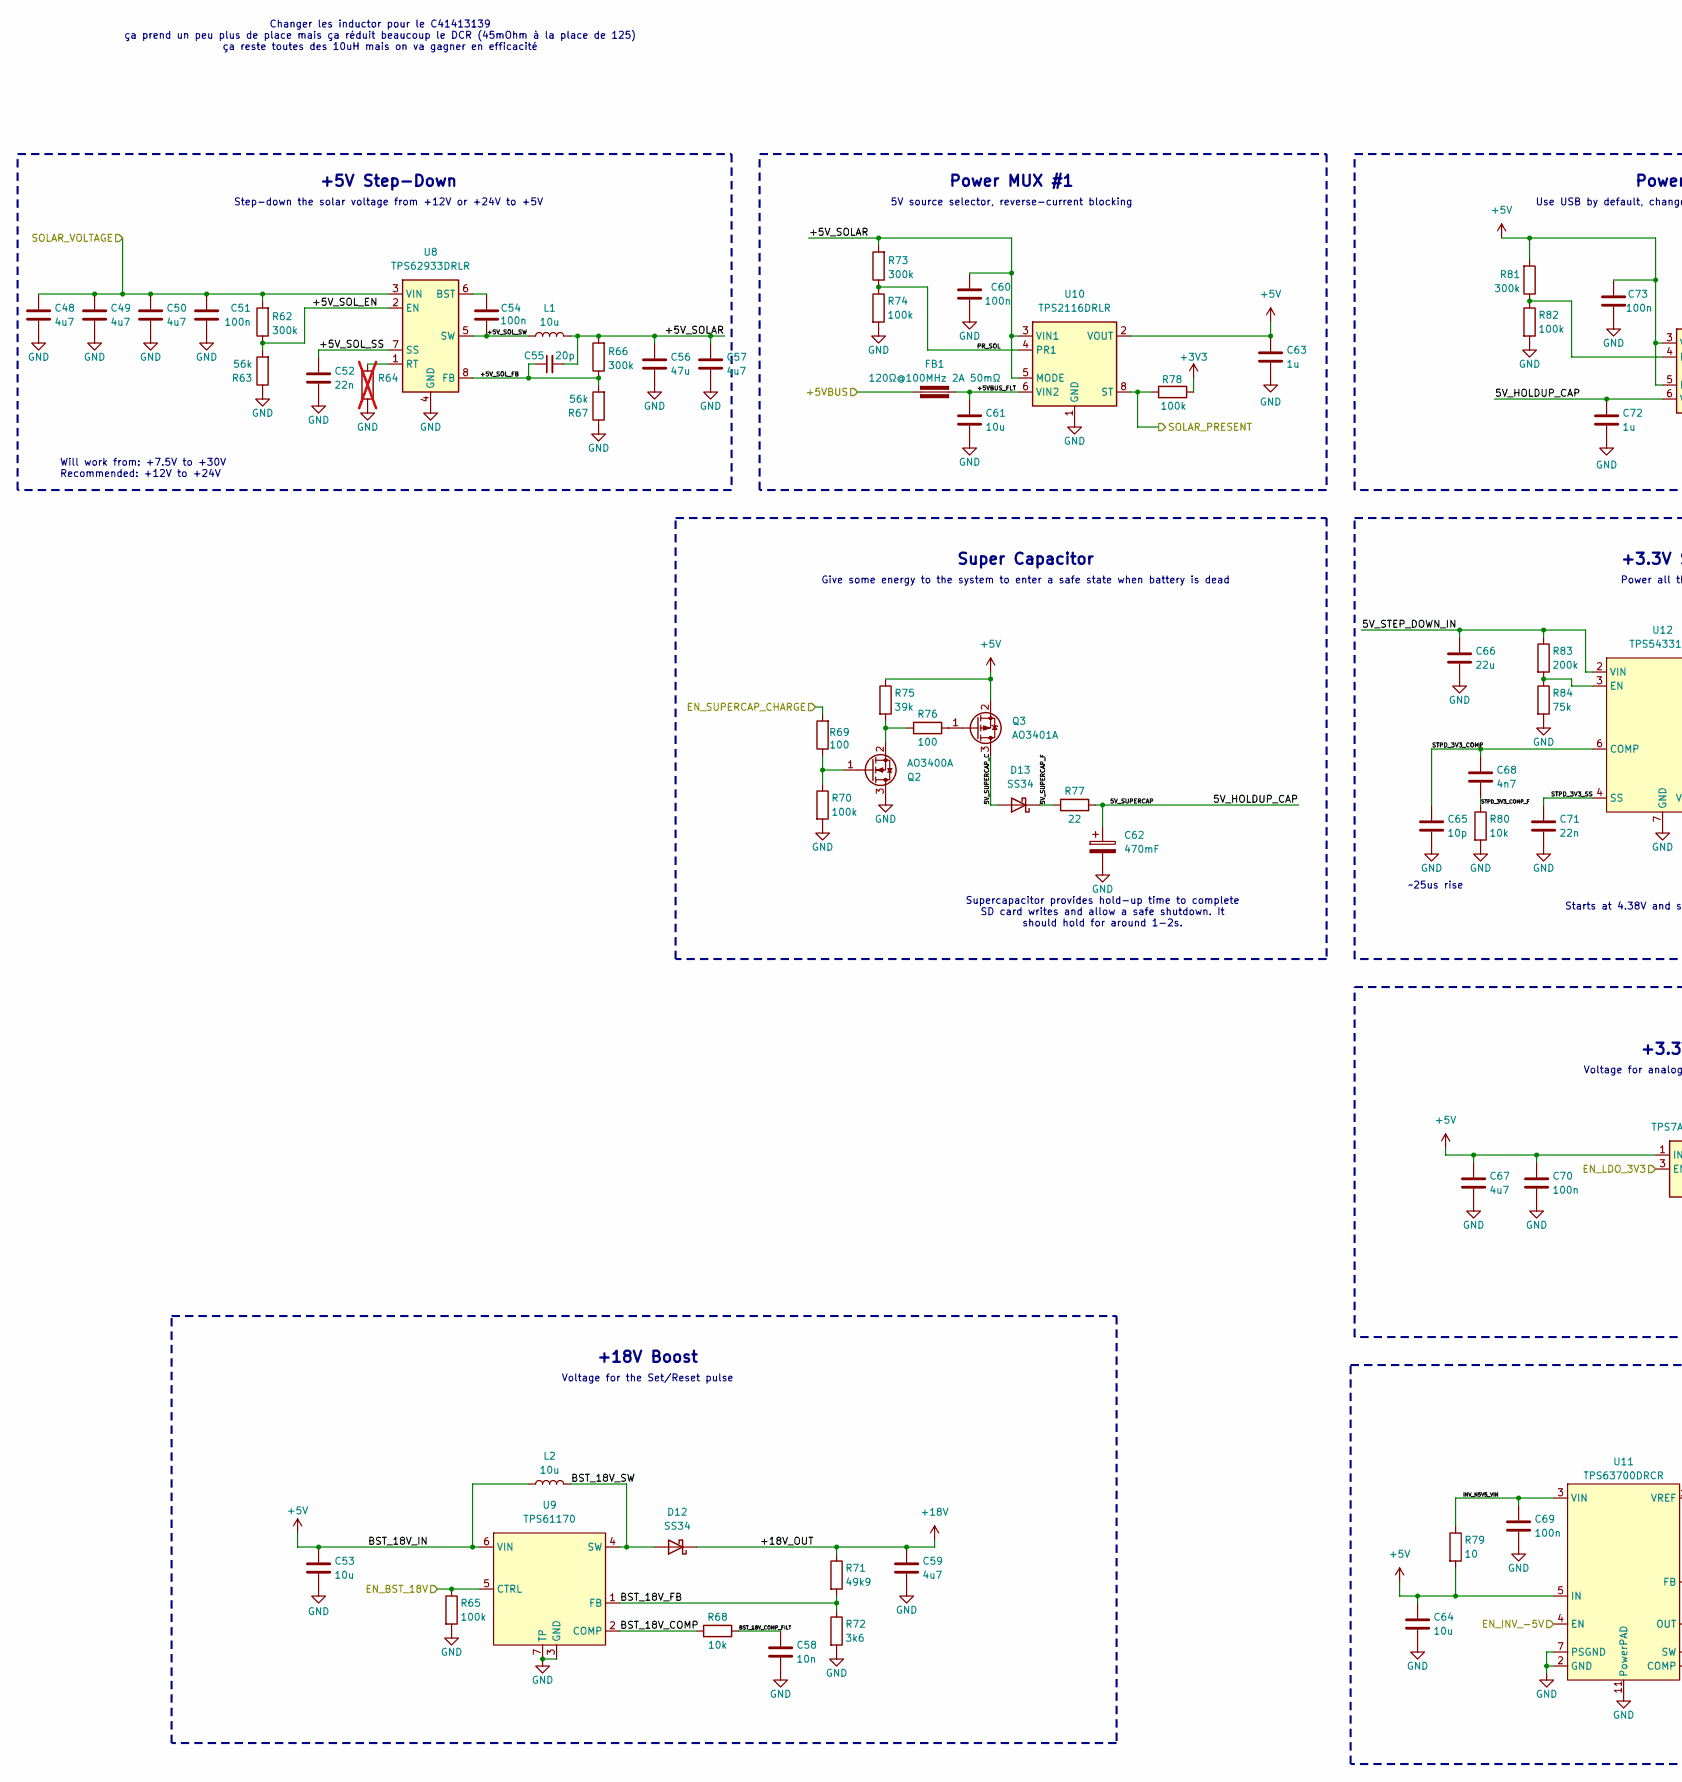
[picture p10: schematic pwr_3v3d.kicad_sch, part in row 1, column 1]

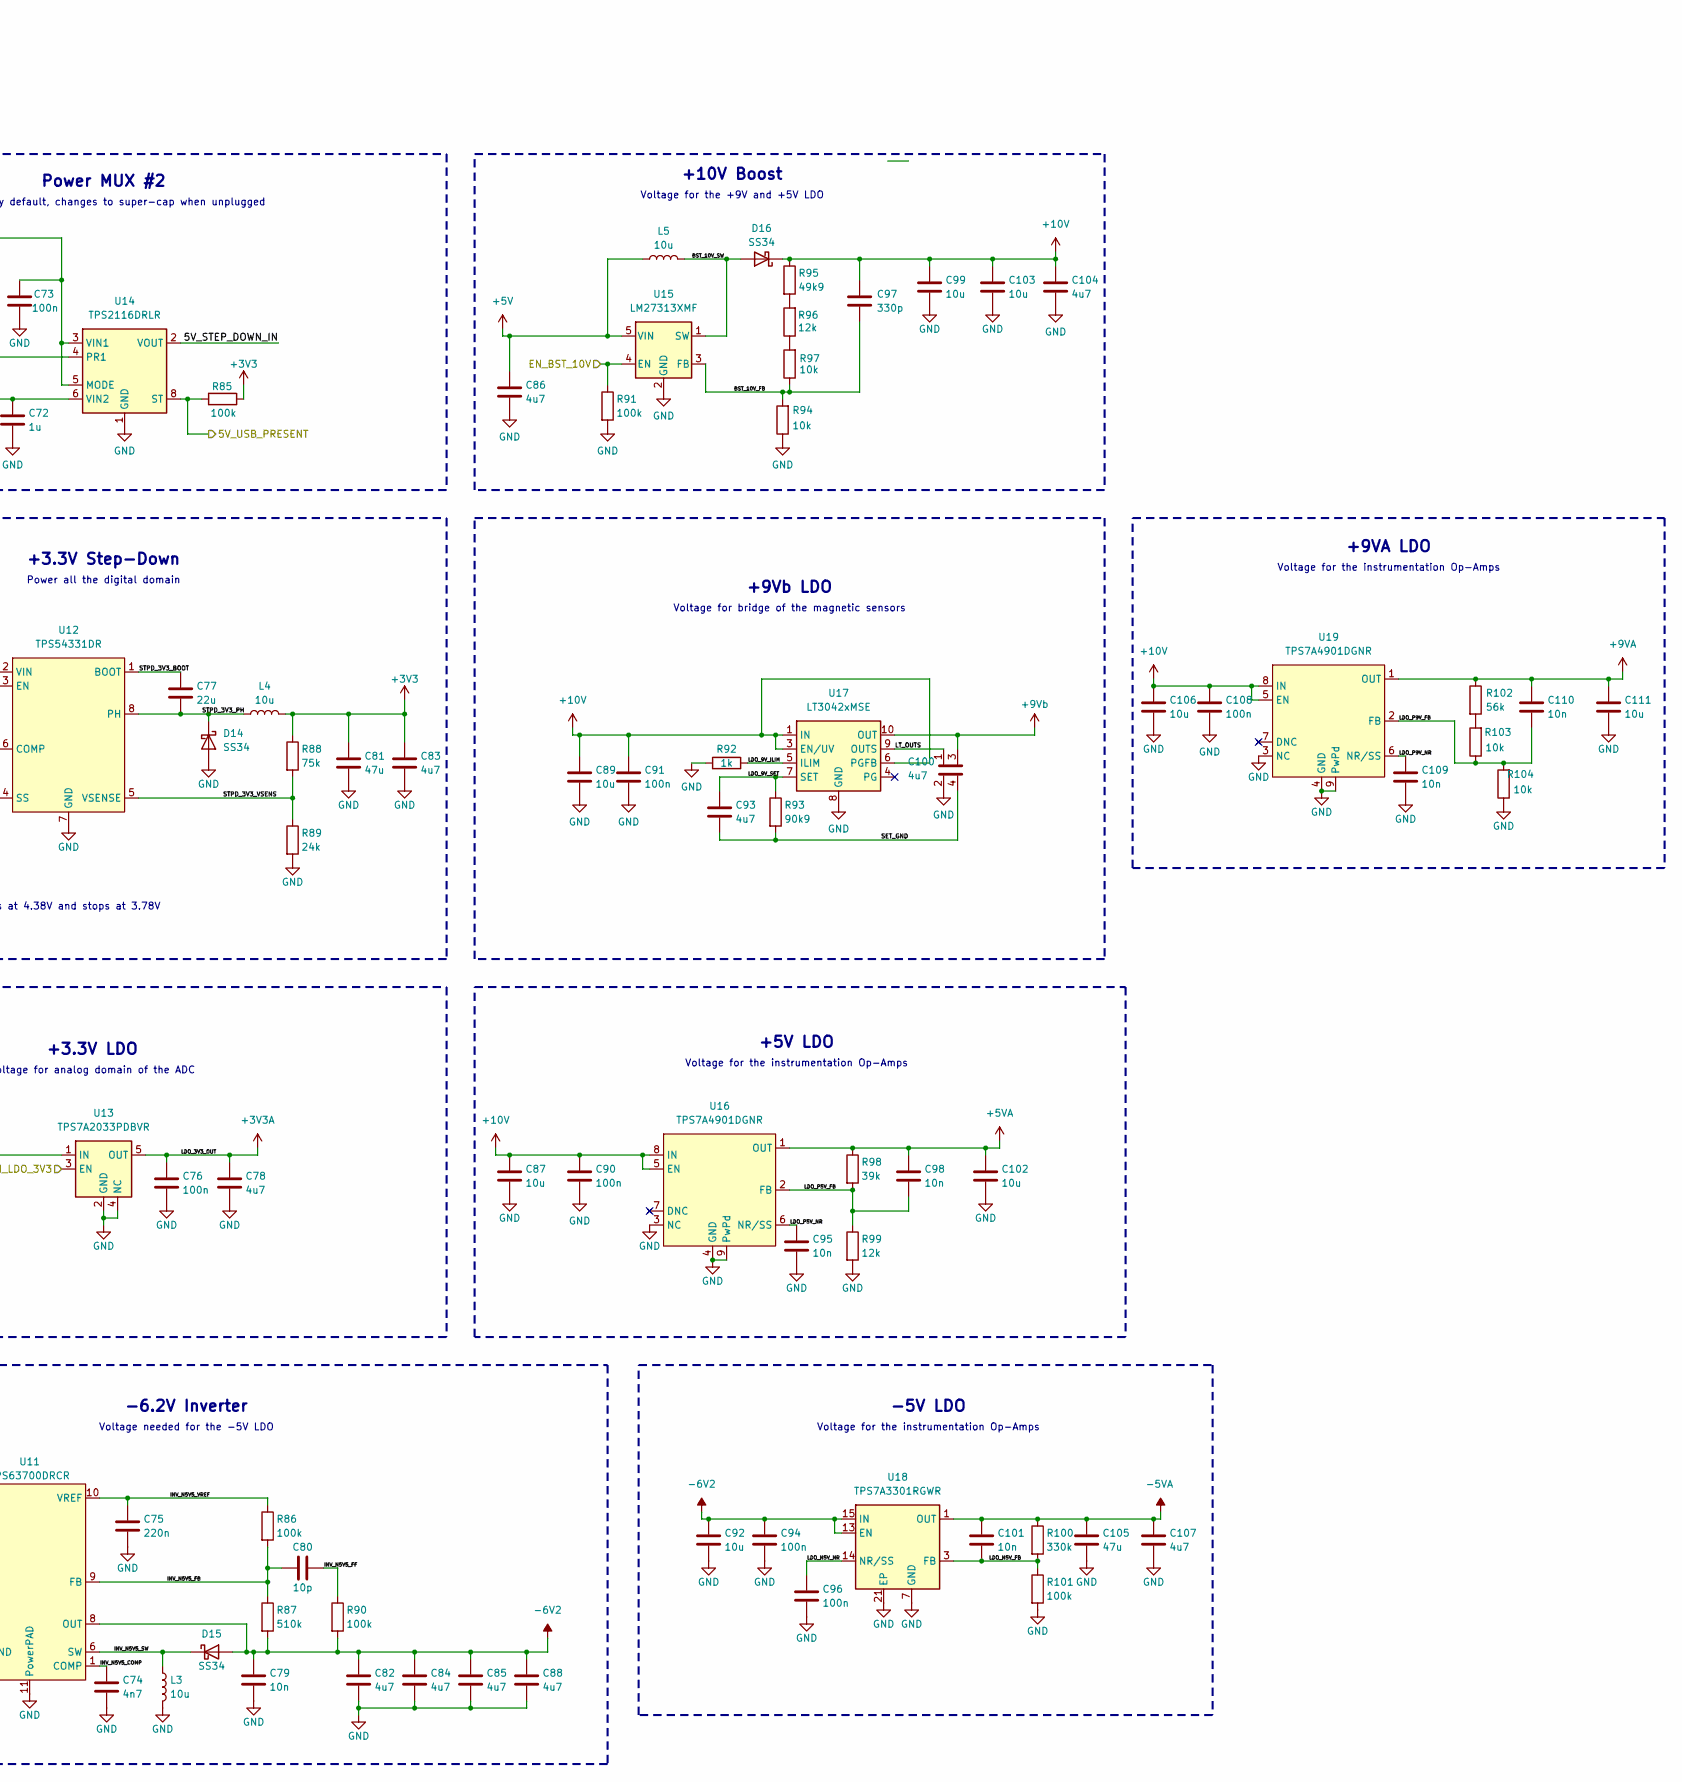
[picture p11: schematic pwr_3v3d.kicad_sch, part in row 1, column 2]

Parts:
C48, C49, C50, C57, C59, C67, C78, C82, C83, C84, C85, C86, C88, C93, C104, C107: 4u7; C_1206_3216Metric; LCSC C29823
C51, C54, C60, C69, C70, C73, C76, C90, C91, C94, C96, C108: 100n; C_0603_1608Metric; LCSC C14663
C52, C71: 22n; C_0603_1608Metric; LCSC C21122
C53, C61, C64, C87, C89, C92, C99, C102, C103, C106, C111: 10u; C_0805_2012Metric; LCSC C15850
C55: 20p; C_0402_1005Metric; LCSC C1554
C56, C81, C105: 47u; C_1206_3216Metric; LCSC C96123
C58, C79, C95, C98, C101, C109, C110: 10n; C_0603_1608Metric; LCSC C57112
C62: 470mF; C_Radial_D8.0mm_P11.50mm
C63, C72: 1u; C_0805_2012Metric; LCSC C28323
C65, C80: 10p; C_0603_1608Metric; LCSC C1634
C66, C77: 22u; C_1206_3216Metric; LCSC C12891
C68, C74: 4n7; C_0603_1608Metric; LCSC C53987
C75: 220n; C_0603_1608Metric; LCSC C21120
C97: 330p; C_0603_1608Metric; LCSC C1664
C100: 4u7; kelvin_connect_1206_SMD_CAP; LCSC C29823
D12, D13, D14, D15, D16: SS34; D_SMA; LCSC C8678
FB1: 120Ω@100MHz 2A 50mΩ; L_0603_1608Metric; LCSC C14709
L1, L2, L3, L4, L5: 10u; L_Sunlord_MWSA0503S; LCSC C177248
Q2: AO3400A; SOT-23; LCSC C20917
Q3: AO3401A; SOT-23; LCSC C15127
R62, R66, R73, R81: 300k; R_0603_1608Metric; LCSC C23024
R63, R67, R102: 56k; R_0603_1608Metric; LCSC C23206
R64: R_0603_1608Metric; not fitted
R65, R70, R74, R78, R82, R85, R86, R90, R91, R101: 100k; R_0603_1608Metric; LCSC C25803
R68, R80, R94, R97, R103, R104: 10k; R_0603_1608Metric; LCSC C25804
R69, R76: 100; R_0805_2012Metric; LCSC C17408
R71, R95: 49k9; R_0603_1608Metric; LCSC C23184
R72: 3k6; R_0603_1608Metric; LCSC C22980
R75, R98: 39k; R_0603_1608Metric; LCSC C23153
R77: 22; R_2512_6332Metric; LCSC C2974113
R79: 10; R_0603_1608Metric; LCSC C22859
R83: 200k; R_0603_1608Metric; LCSC C25811
R84, R88: 75k; R_0603_1608Metric; LCSC C23242
R87: 510k; R_0603_1608Metric; LCSC C23192
R89: 24k; R_0603_1608Metric; LCSC C23352
R92: 1k; R_0603_1608Metric; LCSC C21190
R93: 90k9; R_1206_3216Metric; LCSC C870933
R96, R99: 12k; R_0603_1608Metric; LCSC C22790
R100: 330k; R_0603_1608Metric; LCSC C23137
U8: TPS62933DRLR; SOT-583-8; LCSC C3200405
U9: TPS61170; WSON-6-1EP_2x2mm_P0.65mm_EP1x1.6mm; LCSC C15163
U10, U14: TPS2116DRLR; SOT-583-8; LCSC C3235557
U11: TPS63700DRCR; VSON-10-1EP_3x3mm_P0.5mm_EP1.2x2mm; LCSC C54792
U12: TPS54331DR; SOIC-8_3.9x4.9mm_P1.27mm; LCSC C9865
U13: TPS7A2033PDBVR; SOT-23-5; LCSC C2862740
U15: LM27313XMF; SOT-23-5; LCSC C341750
U16, U19: TPS7A4901DGNR; HVSSOP-8-1EP_3x3mm_P0.65mm_EP1.57x1.89mm; LCSC C16430
U17: LT3042xMSE; MSOP-10-1EP_3x3mm_P0.5mm_EP1.68x1.88mm; LCSC C461518
U18: TPS7A3301RGWR; Texas_RGW0020A_VQFN-20-1EP_5x5mm_P0.65mm_EP3.15x3.15mm; LCSC C90082

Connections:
+3V3: C81.1, C83.1, L4.2, R78.1, R85.1, R88.1; also elsewhere on the board
+3V3A: C76.1, C78.1, U13.5 (OUT); also elsewhere on the board
+5V: C53.1, C63.1, C64.1, C67.1, C70.1, C73.2, C86.1, L2.1, L5.1, Q3.2, R75.1, R79.2, R81.2, U9.6 (VIN), U10.2 (VOUT), U10.7 (VOUT), U11.5 (IN), U13.1 (IN), U14.3 (VIN1), U14.5 (MODE), U15.5 (VIN)
+5VA: C98.1, C102.1, R98.1, U16.1 (OUT); also elsewhere on the board
+9VA: C110.1, C111.1, R102.1, U19.1 (OUT); also elsewhere on the board
+9Vb: C100.3, U17.10 (OUT); also elsewhere on the board
+10V: C87.1, C89.1, C90.1, C91.1, C97.1, C99.1, C103.1, C104.1, C106.1, C108.1, D16.1 (K), R95.1, U16.5 (EN), U16.8 (IN), U17.1 (IN), U17.2 (IN), U17.3 (EN/UV), U17.6 (PGFB), U19.5 (EN), U19.8 (IN)
+18V: C59.1, D12.1 (K), R71.1; also elsewhere on the board
-5VA: C101.1, C105.1, C107.1, R100.1, U18.1 (OUT), U18.20 (OUT); also elsewhere on the board
-6V2: C79.1, C82.1, C84.1, C85.1, C88.1, C92.1, C94.1, D15.2 (A), R87.2, R90.2, U11.8 (OUT), U18.13 (EN), U18.15 (IN), U18.16 (IN)
/DATA_SAVING/+5VBUS: FB1.1; also elsewhere on the board
/IO_CONNECTOR/SOLAR_VOLTAGE: C48.1, C49.1, C50.1, C51.2, R62.2, U8.3 (VIN); also elsewhere on the board
/MCU_ESP32S3/5V_USB_PRESENT: R85.2, U14.8 (ST); also elsewhere on the board
/MCU_ESP32S3/EN_BST_10V: R91.1, U15.4 (EN); also elsewhere on the board
/MCU_ESP32S3/EN_BST_18V: R65.1, U9.5 (CTRL); also elsewhere on the board
/MCU_ESP32S3/EN_INV_-5V: U11.4 (EN); also elsewhere on the board
/MCU_ESP32S3/EN_LDO_3V3: U13.3 (EN); also elsewhere on the board
/MCU_ESP32S3/EN_SUPERCAP_CHARGE: R69.2; also elsewhere on the board
/MCU_ESP32S3/SOLAR_PRESENT: R78.2, U10.8 (ST); also elsewhere on the board
/POWER/5V_HOLDUP_CAP: C62.1, C72.1, R77.2, U14.6 (VIN2)
/POWER/5V_STEP_DOWN_IN: C66.1, R83.1, U12.2 (VIN), U14.2 (VOUT), U14.7 (VOUT)
/POWER/5V_SUPERCAP_C: D13.2 (A), Q3.3
/POWER/5V_SUPERCAP_F: D13.1 (K), R77.1
/POWER/+5VBUS_FLT: C61.1, FB1.2, U10.6 (VIN2)
/POWER/+5V_SOLAR: C55.2, C56.1, C57.1, C60.2, L1.2, R66.2, R73.2, U10.3 (VIN1), U10.5 (MODE)
/POWER/+5V_SOL_EN: R62.1, R63.2, U8.2 (EN)
/POWER/+5V_SOL_FB: C55.1, R66.1, R67.2, U8.8 (FB)
/POWER/+5V_SOL_SS: C52.1, U8.7 (SS)
/POWER/+5V_SOL_SW: C54.1, L1.1, U8.5 (SW)
/POWER/BST_10V_FB: C97.2, R94.2, R97.1, U15.3 (FB)
/POWER/BST_10V_SW: D16.2 (A), L5.2, U15.1 (SW)
/POWER/BST_18V_COMP: R68.1, U9.2 (COMP)
/POWER/BST_18V_COMP_FILT: C58.1, R68.2
/POWER/BST_18V_FB: R71.2, R72.1, U9.1 (FB)
/POWER/BST_18V_SW: D12.2 (A), L2.2, U9.4 (SW)
/POWER/INV_N5V5_COMP: C74.1, U11.1 (COMP)
/POWER/INV_N5V5_FB: C80.1, R86.2, R87.1, U11.9 (FB)
/POWER/INV_N5V5_FF: C80.2, R90.1
/POWER/INV_N5V5_SW: D15.1 (K), L3.1, U11.6 (SW)
/POWER/INV_N5V5_VIN: C69.1, R79.1, U11.3 (VIN)
/POWER/INV_N5V5_VREF: C75.1, R86.1, U11.10 (VREF)
/POWER/LDO_9V_ILIM: R92.2, U17.5 (ILIM)
/POWER/LDO_9V_SET: C93.1, R93.1, U17.7 (SET)
/POWER/LDO_N5V_FB: C101.2, R100.2, R101.1, U18.3 (FB)
/POWER/LDO_N5V_NR: C96.1, U18.14 (NR/SS)
/POWER/LDO_P5V_FB: C98.2, R98.2, R99.1, U16.2 (FB)
/POWER/LDO_P5V_NR: C95.1, U16.6 (NR/SS)
/POWER/LDO_P9V_FB: C110.2, R103.1, R104.2, U19.2 (FB)
/POWER/LDO_P9V_NR: C109.1, U19.6 (NR/SS)
/POWER/LT_OUTS: C100.1, U17.9 (OUTS)
/POWER/PR_SOL: R73.1, R74.1, U10.4 (PR1)
/POWER/SET_GND: C93.2, C100.4, R93.2
/POWER/STPD_3V3_BOOT: C77.1, U12.1 (BOOT)
/POWER/STPD_3V3_COMP: C65.1, C68.1, U12.6 (COMP)
/POWER/STPD_3V3_COMP_F: C68.2, R80.1
/POWER/STPD_3V3_PH: C77.2, D14.1 (K), L4.1, U12.8 (PH)
/POWER/STPD_3V3_SS: C71.1, U12.4 (SS)
/POWER/STPD_3V3_VSENS: R88.2, R89.1, U12.5 (VSENSE)
GND: C48.2, C49.2, C50.2, C51.1, C52.2, C53.2, C56.2, C57.2, C58.2, C59.2, C60.1, C61.2, C62.2, C63.2, C64.2, C65.2, C66.2, C67.2, C69.2, C70.2, C71.2, C72.2, C73.1, C74.2, C75.2, C76.2, C78.2, C79.2, C81.2, C82.2, C83.2, C84.2, C85.2, C86.2, C87.2, C88.2, C89.2, C90.2, C91.2, C92.2, C94.2, C95.2, C96.2, C99.2, C100.2, C102.2, C103.2, C104.2, C105.2, C106.2, C107.2, C108.2, C109.2, C111.2, D14.2 (A), L3.2, Q2.3 (D), R63.1, R64.2, R65.2, R67.1, R70.2, R72.2, R74.2, R80.2, R82.2, R84.2, R89.2, R91.2, R92.1, R94.1, R99.2, R101.2, R104.1, U8.4 (GND), U9.3 (GND), U9.7 (TP), U10.1 (GND), U11.2 (GND), U11.7 (PSGND), U11.11 (PowerPAD), U12.7 (GND), U13.2 (GND), U13.4 (NC), U14.1 (GND), U15.2 (GND), U16.3 (NC), U16.4 (GND), U16.9 (PwPd), U17.8 (GND), U17.11 (GND), U18.7 (GND), U18.21 (EP), U19.3 (NC), U19.4 (GND), U19.9 (PwPd); also elsewhere on the board
unnamed: Q2.1 (G), R69.1, R70.1
unnamed: Q2.2 (S), R75.2, R76.1
unnamed: Q3.1, R76.2
unnamed: R95.2, R96.2
unnamed: R96.1, R97.2
unnamed: R102.2, R103.2
unnamed: C54.2, U8.6 (BST)
unnamed: R64.1, U8.1 (RT)
unnamed: R83.2, R84.1, U12.3 (EN)
unnamed: R81.1, R82.1, U14.4 (PR1)

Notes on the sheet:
Changer les inductor pour le C41413139 ça prend un peu plus de place mais ça réduit beaucoup le DCR (45mOhm à la place de 125) ça reste toutes des 10uH mais on va gagner en efficacité
Voltage for the instrumentation Op-Amps
-6.2V Inverter
+5V Step-Down
5V source selector, reverse-current blocking
Use USB by default, changes to super-cap when unplugged
~25us rise
Voltage for the +9V and +5V LDO
Super Capacitor
Voltage for analog domain of the ADC
+5V LDO
+3.3V LDO
Voltage needed for the -5V LDO
+10V Boost
Give some energy to the system to enter a safe state when battery is dead
Power MUX #1
+3.3V Step-Down
+9VA LDO
+9Vb LDO
Step-down the solar voltage from +12V or +24V to +5V
Power all the digital domain
+18V Boost
Starts at 4.38V and stops at 3.78V
Supercapacitor provides hold-up time to complete SD card writes and allow a safe shutdown. It should hold for around 1-2s.
Will work from: +7.5V to +30V Recommended: +12V to +24V
-5V LDO
Voltage for bridge of the magnetic sensors
Power MUX #2
Voltage for the Set/Reset pulse

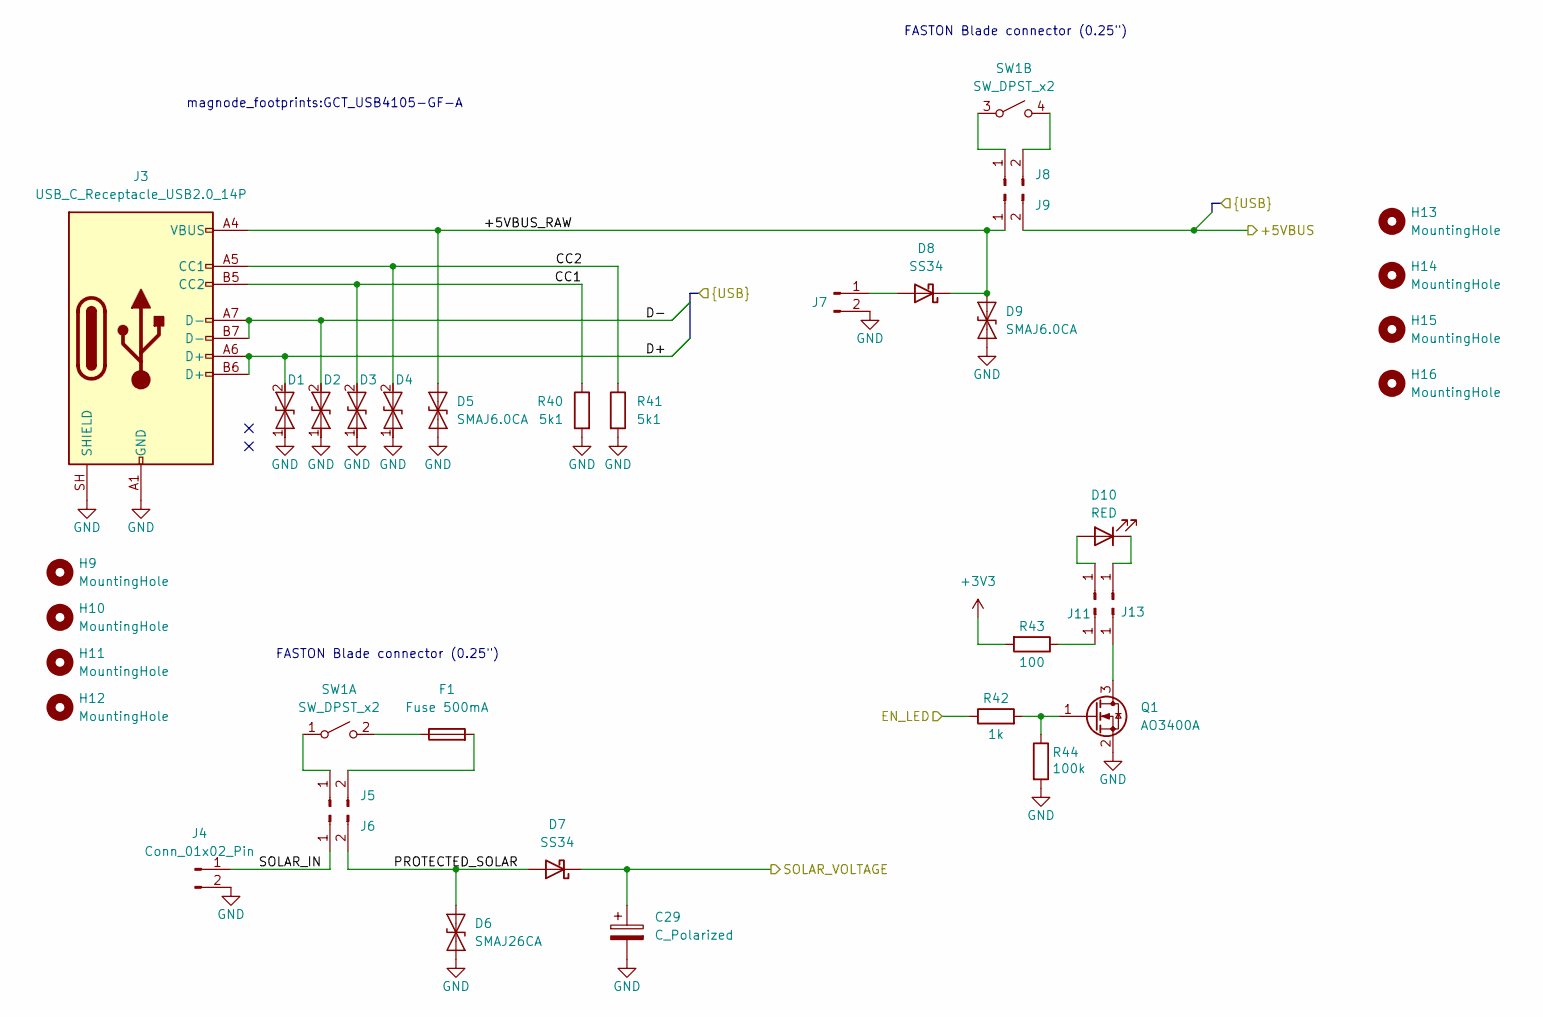
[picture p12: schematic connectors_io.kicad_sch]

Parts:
C29: C_Polarized; CP_Radial_D10.0mm_P5.00mm
D1, D2, D3, D4: H5VUD5BB; D_SOD-523; LCSC C20615820
D5: SMAJ6.0CA; D_SMA
D6: SMAJ26CA; D_SMA; LCSC SMAJ26CA
D7, D8: SS34; D_SMA; LCSC C8678
D9: SMAJ6.0CA; D_SMA; LCSC C19077526
D10: RED
F1: Fuse 500mA
H9, H10, H11, H12, H13, H14, H15, H16: MountingHole; MountingHole_4.3mm_M4
J3: USB_C_Receptacle_USB2.0_14P; AMPHENOL_12402054M611A
J4, J6, J7, J9: Conn_01x02_Pin; KEYSTONE_7817
J5, J8: Conn_01x02_Pin
J10, J12: Conn_01x01_Pin
J11, J13: Conn_01x01_Pin; KEYSTONE_1267
Q1: AO3400A; SOT-23; LCSC C20917
R40, R41: 5k1; R_0603_1608Metric; LCSC C23186
R42: 1k; R_0603_1608Metric; LCSC C21190
R43: 100; R_0805_2012Metric; LCSC C17408
R44: 100k; R_0603_1608Metric; LCSC C25803
SW1: SW_DPST_x2

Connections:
+3V3: R43.2; also elsewhere on the board
/DATA_SAVING/+5VBUS: J9.2; also elsewhere on the board
/DATA_SAVING/CC1: D3.2, J3.B5 (CC2), R40.1
/DATA_SAVING/CC2: D4.2, J3.A5 (CC1), R41.1
/DATA_SAVING/D+: D1.2, J3.A6 (D+), J3.B6 (D+); also elsewhere on the board
/DATA_SAVING/D-: D2.2, J3.A7 (D-), J3.B7 (D-); also elsewhere on the board
/IO_CONNECTOR/+5VBUS_RAW: D5.2 (A2), D8.1 (K), D9.2 (A2), J3.A4 (VBUS), J3.A9 (VBUS), J3.B4 (VBUS), J3.B9 (VBUS), J9.1
/IO_CONNECTOR/EN_LED: R42.1; also elsewhere on the board
/IO_CONNECTOR/PROTECTED_SOLAR: D6.2 (A2), D7.2 (A), J6.2
/IO_CONNECTOR/SOLAR_IN: J4.1, J6.1
/IO_CONNECTOR/SOLAR_VOLTAGE: C29.1, D7.1 (K); also elsewhere on the board
GND: C29.2, D1.1, D2.1, D3.1, D4.1, D5.1 (A1), D6.1 (A1), D9.1 (A1), J3.A1 (GND), J3.A12 (GND), J3.B1 (GND), J3.B12 (GND), J3.SH (SHIELD), J4.2, J7.2, Q1.2 (S), R40.2, R41.2, R44.2; also elsewhere on the board
unnamed: D8.2 (A), J7.1
unnamed: D10.1 (K), J12.1
unnamed: D10.2 (A), J10.1
unnamed: F1.1, SW1.2 (B)
unnamed: F1.2, J5.2
unnamed: J5.1, SW1.1 (A)
unnamed: J8.1, SW1.3 (A)
unnamed: J8.2, SW1.4 (B)
unnamed: J11.1 (Pin_1_1), R43.1
unnamed: J13.1 (Pin_1_1), Q1.3 (D)
unnamed: Q1.1 (G), R42.2, R44.1

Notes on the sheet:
FASTON Blade connector (0.25")
magnode_footprints:GCT_USB4105-GF-A


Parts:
C4, C6, C8, C9, C10, C20, C22, C23, C24, C26, C28: 100n; C_0603_1608Metric; LCSC C14663
C5, C27: 10u; C_0805_2012Metric; LCSC C15850
C7: 47u; C_1206_3216Metric; LCSC C96123
C11, C21, C25: 1u; C_0805_2012Metric; LCSC C28323
C12, C13, C14, C15, C16, C17, C18, C19: 1n; C_0603_1608Metric; LCSC C1588
R13, R39: 1k; R_0603_1608Metric; LCSC C21190
R14, R15, R16, R17, R18, R19, R20, R21, R22, R23, R24, R25, R26, R27, R28, R29, R33, R34: 22; R_0603_1608Metric; LCSC C23345
R30, R31, R32, R37, R38: 100k; R_0603_1608Metric; LCSC C25803
R35: 10k; R_0603_1608Metric; LCSC C25804
R36: 300k; R_0603_1608Metric; LCSC C23024
U4: AD7779ACPZ; QFN-64-1EP_9x9mm_P0.5mm_EP7.65x7.65mm; LCSC C398822
Y1: OT2JI-111-8.192M; Crystal_SMD_3225-4Pin_3.2x2.5mm; LCSC C7425393

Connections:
+1V65: U4.57 (VCM); also elsewhere on the board
+3V3: C24.1, C26.1, C27.1, R32.1, R35.2, R38.1, U4.24 (IOVDD), Y1.4 (VDD); also elsewhere on the board
+3V3A: C5.1, C8.1, C10.1, C20.1, C22.1, C23.1, U4.6 (AVDD1A), U4.43 (AVDD1B), U4.52 (AVDD2B), U4.54 (FORMAT1), U4.55 (FORMAT0), U4.58 (AVDD2A), U4.62 (AVDD4); also elsewhere on the board
+9Vb: R36.1; also elsewhere on the board
/ADC_AD777x/ADC_9VA_MON: C28.1, R36.2, R37.1, R39.1
/ADC_AD777x/ADC_9VA_MON_FLT: R39.2, U4.63 (AUXAIN+)
/ADC_AD777x/ADC_AREG1CAP: C11.1, U4.59 (AREG1CAP)
/ADC_AD777x/ADC_AREG2CAP: C21.1, U4.51 (AREG2CAP)
/ADC_AD777x/ADC_CONVST_SAR: R30.1, U4.17 (CONVST_SAR); also elsewhere on the board
/ADC_AD777x/ADC_CS: R35.1, U4.18 (ALERT/~CS); also elsewhere on the board
/ADC_AD777x/ADC_DRDY: R34.2; also elsewhere on the board
/ADC_AD777x/ADC_DRDY_R: R34.1, U4.30 (~DRDY)
/ADC_AD777x/ADC_DREGCAP: C25.1, U4.23 (DREGCAP)
/ADC_AD777x/ADC_IN0+: C12.1, R14.2, U4.2 (AIN0+)
/ADC_AD777x/ADC_IN0-: C12.2, R15.2, U4.1 (AIN0-)
/ADC_AD777x/ADC_IN1+: C13.1, R16.2, U4.4 (AIN1+)
/ADC_AD777x/ADC_IN1-: C13.2, R17.2, U4.3 (AIN1-)
/ADC_AD777x/ADC_IN2+: C14.1, R18.2, U4.10 (AIN2+)
/ADC_AD777x/ADC_IN2-: C14.2, R19.2, U4.9 (AIN2-)
/ADC_AD777x/ADC_IN3+: C15.1, R20.2, U4.12 (AIN3+)
/ADC_AD777x/ADC_IN3-: C15.2, R21.2, U4.11 (AIN3-)
/ADC_AD777x/ADC_IN4+: C16.1, R22.2, U4.47 (AIN4+)
/ADC_AD777x/ADC_IN4-: C16.2, R23.2, U4.48 (AIN4-)
/ADC_AD777x/ADC_IN5+: C17.1, R24.2, U4.45 (AIN5+)
/ADC_AD777x/ADC_IN5-: C17.2, R25.2, U4.46 (AIN5-)
/ADC_AD777x/ADC_IN6+: C18.1, R26.2, U4.39 (AIN6+)
/ADC_AD777x/ADC_IN6-: C18.2, R27.2, U4.40 (AIN6-)
/ADC_AD777x/ADC_IN7+: C19.1, R28.2, U4.37 (AIN7+)
/ADC_AD777x/ADC_IN7-: C19.2, R29.2, U4.38 (AIN7-)
/ADC_AD777x/ADC_MCLK: U4.32 (XTAL2/MCLK), Y1.3 (OUT)
/ADC_AD777x/ADC_MCLK_EN: R38.2, Y1.1 (Tri-State); also elsewhere on the board
/ADC_AD777x/ADC_REF+: C4.1, C6.1, C7.1, R13.1, U4.8 (REF1+), U4.41 (REF2+)
/ADC_AD777x/ADC_REF_OUT: C9.1, R13.2, U4.49 (REF_OUT)
/ADC_AD777x/ADC_RESET: R32.2, U4.36 (~RESET); also elsewhere on the board
/ADC_AD777x/ADC_SCLK: U4.19 (DCLK2/SCLK); also elsewhere on the board
/ADC_AD777x/ADC_SDI: U4.20 (DCLK1/SDI); also elsewhere on the board
/ADC_AD777x/ADC_SDO: R33.2; also elsewhere on the board
/ADC_AD777x/ADC_SDO_R: R33.1, U4.21 (DCLK0/SDO)
/ADC_AD777x/ADC_START: R31.1, U4.33 (~START); also elsewhere on the board
/ADC_AD777x/AIN0+: R14.1; also elsewhere on the board
/ADC_AD777x/AIN0-: R15.1; also elsewhere on the board
/ADC_AD777x/AIN1+: R16.1; also elsewhere on the board
/ADC_AD777x/AIN1-: R17.1; also elsewhere on the board
/ADC_AD777x/AIN2+: R18.1; also elsewhere on the board
/ADC_AD777x/AIN2-: R19.1; also elsewhere on the board
/ADC_AD777x/AIN4+: R22.1; also elsewhere on the board
/ADC_AD777x/AIN4-: R23.1; also elsewhere on the board
/ADC_AD777x/AIN5+: R24.1; also elsewhere on the board
/ADC_AD777x/AIN5-: R25.1; also elsewhere on the board
/ADC_AD777x/AIN6+: R26.1; also elsewhere on the board
/ADC_AD777x/AIN6-: R27.1; also elsewhere on the board
/ADC_AD777x/TH1+: R20.1; also elsewhere on the board
/ADC_AD777x/TH1-: R21.1; also elsewhere on the board
/ADC_AD777x/TH2+: R28.1; also elsewhere on the board
/ADC_AD777x/TH2-: R29.1; also elsewhere on the board
GND: C4.2, C5.2, C6.2, C7.2, C8.2, C9.2, C10.2, C11.2, C20.2, C21.2, C22.2, C23.2, C24.2, C25.2, C26.2, C27.2, C28.2, R30.2, R31.2, R37.2, U4.5 (AVSS1A), U4.7 (REF1-), U4.22 (DGND), U4.31 (XTAL1), U4.42 (REF2-), U4.44 (AVSS1B), U4.50 (AVSS2B), U4.53 (AVSS3), U4.56 (CLK_SEL), U4.60 (AVSS2A), U4.61 (AVSS4), U4.64 (AUXAIN-), U4.65 (EPAD(AVSSx)), Y1.2 (GND); also elsewhere on the board
unnamed: U4.34 (~SYNC_OUT), U4.35 (~SYNC_IN)

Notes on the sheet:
Vérifier clock specks vs température


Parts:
C1, C2: 100n; C_0603_1608Metric; LCSC C14663
C3: 10u; C_0805_2012Metric; LCSC C15850
R7, R8, R9: 10k; R_0603_1608Metric; LCSC C25804
R10, R11, R12: 22; R_0603_1608Metric; LCSC C23345
U1, U2: 74HC595D,118; SOIC-16_3.9x9.9mm_P1.27mm; LCSC C5947
U3: ESP32-S3-DevKitC; MODULE_ESP32-S3-DEVKITC

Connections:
+3V3: C1.1, C2.1, C3.1, R7.1, R8.1, R9.1, U1.16 (VCC), U2.16 (VCC), U3.1 (ESP_3V3), U3.2 (ESP_3V3); also elsewhere on the board
/ADC_AD777x/ADC_CONVST_SAR: U2.5 (QF); also elsewhere on the board
/ADC_AD777x/ADC_CS: R10.1; also elsewhere on the board
/ADC_AD777x/ADC_DRDY: U3.16 (GPIO10); also elsewhere on the board
/ADC_AD777x/ADC_MCLK_EN: U2.4 (QE); also elsewhere on the board
/ADC_AD777x/ADC_RESET: U2.2 (QC); also elsewhere on the board
/ADC_AD777x/ADC_SCLK: R11.1; also elsewhere on the board
/ADC_AD777x/ADC_SDI: R12.1; also elsewhere on the board
/ADC_AD777x/ADC_SDO: U3.20 (GPIO14); also elsewhere on the board
/ADC_AD777x/ADC_START: U2.3 (QD); also elsewhere on the board
/DATA_SAVING/EN_SD_MUX: U1.6 (QG); also elsewhere on the board
/DATA_SAVING/E_CLK: U3.7 (GPIO7); also elsewhere on the board
/DATA_SAVING/E_CMD: U3.9 (GPIO16); also elsewhere on the board
/DATA_SAVING/E_D0: U3.5 (GPIO5); also elsewhere on the board
/DATA_SAVING/E_D1: U3.4 (GPIO4); also elsewhere on the board
/DATA_SAVING/E_D2: U3.8 (GPIO15); also elsewhere on the board
/DATA_SAVING/E_D3: U3.6 (GPIO6); also elsewhere on the board
/DATA_SAVING/SD_MUX_SEL: U1.15 (QA); also elsewhere on the board
/DATA_SAVING/USB2641_nRESET: U1.5 (QF); also elsewhere on the board
/DEVICE_DETECT_1: U3.13 (GPIO3); also elsewhere on the board
/DEVICE_DETECT_2: U3.12 (GPIO8); also elsewhere on the board
/GNSS/ESP32_GPS_RX: U3.37 (GPIO45); also elsewhere on the board
/GNSS/ESP32_GPS_TX: U3.38 (GPIO48); also elsewhere on the board
/IMU/CS_LSM: U3.14 (GPIO46); also elsewhere on the board
/IMU/MISO: U3.15 (GPIO9); also elsewhere on the board
/IMU/MOSI: U3.11 (GPIO18); also elsewhere on the board
/IMU/SCLK: U3.10 (GPIO17); also elsewhere on the board
/IO_CONNECTOR/EN_LED: U1.7 (QH); also elsewhere on the board
/MCU_ESP32S3/5V_USB_PRESENT: U3.27 (GPIO2); also elsewhere on the board
/MCU_ESP32S3/EN_BST_10V: U1.2 (QC); also elsewhere on the board
/MCU_ESP32S3/EN_BST_18V: U1.3 (QD); also elsewhere on the board
/MCU_ESP32S3/EN_INV_-5V: U1.4 (QE); also elsewhere on the board
/MCU_ESP32S3/EN_LDO_3V3: U1.1 (QB); also elsewhere on the board
/MCU_ESP32S3/EN_SUPERCAP_CHARGE: U3.28 (GPIO42); also elsewhere on the board
/MCU_ESP32S3/ESP_CS: R10.2, U3.17 (GPIO11)
/MCU_ESP32S3/ESP_SCLK: R11.2, U3.18 (GPIO12)
/MCU_ESP32S3/ESP_SDO: R12.2, U3.19 (GPIO13)
/MCU_ESP32S3/SOLAR_PRESENT: U3.26 (GPIO1); also elsewhere on the board
/MCU_ESP32S3/SR_CHAIN_DATA: U1.9 (QH'), U2.14 (SER)
/MCU_ESP32S3/SR_DATA: U1.14 (SER), U3.39 (GPIO47)
/MCU_ESP32S3/SR_LATCH: U1.12 (RCLK), U2.12 (RCLK), U3.41 (GPIO20)
/MCU_ESP32S3/SR_OE_N: R9.2, U1.13 (~OE), U2.13 (~OE), U3.40 (GPIO21)
/MCU_ESP32S3/SR_SHIFT_CLK: U1.11 (SRCLK), U2.11 (SRCLK), U3.42 (GPIO19)
/MCU_ESP32S3/~SRCLR1: R7.2, U1.10 (~SRCLR)
/MCU_ESP32S3/~SRCLR2: R8.2, U2.10 (~SRCLR)
/RESET_1: U2.6 (QG); also elsewhere on the board
/RESET_2: U2.15 (QA); also elsewhere on the board
/SCL_1: U3.30 (GPIO40); also elsewhere on the board
/SCL_2: U3.32 (GPIO38); also elsewhere on the board
/SDA_1: U3.29 (GPIO41); also elsewhere on the board
/SDA_2: U3.31 (GPIO39); also elsewhere on the board
/SET_1: U2.7 (QH); also elsewhere on the board
/SET_2: U2.1 (QB); also elsewhere on the board
GND: C1.2, C2.2, C3.2, U1.8 (GND), U2.8 (GND), U3.22 (GND), U3.23 (GND), U3.43 (GND), U3.44 (GND); also elsewhere on the board

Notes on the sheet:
Shift register
Expand the number of GPIO
ESP32-S3-WROOM-1
MCU with antenna for Bluetooth/Wifi

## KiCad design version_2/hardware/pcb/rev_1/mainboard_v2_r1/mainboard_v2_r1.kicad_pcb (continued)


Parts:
C47: 10u; C_0805_2012Metric; LCSC C15850
J15: Conn_01x08; MAX_M10S_WITH_HEADER

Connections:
+3V3: C47.1, J15.2; also elsewhere on the board
/GNSS/ESP32_GPS_RX: J15.4; also elsewhere on the board
/GNSS/ESP32_GPS_TX: J15.5; also elsewhere on the board
GND: C47.2, J15.1; also elsewhere on the board


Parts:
H1, H2, H3, H4: MountingHole; MountingHole_4.3mm_M4
J1: 550910374; CON_550910374_MOL
R1, R2: 100k; R_0603_1608Metric; LCSC C25803
R3: 10k; R_0603_1608Metric; LCSC C25804

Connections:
+1V65: J1.2; also elsewhere on the board
+3V3: J1.9, R3.2; also elsewhere on the board
+3V3A: J1.8; also elsewhere on the board
+5VA: J1.4; also elsewhere on the board
+9VA: J1.6; also elsewhere on the board
+9Vb: J1.7; also elsewhere on the board
+18V: J1.3; also elsewhere on the board
-5VA: J1.5; also elsewhere on the board
/ADC_AD777x/AIN0+: J1.25; also elsewhere on the board
/ADC_AD777x/AIN0-: J1.26; also elsewhere on the board
/ADC_AD777x/AIN1+: J1.22; also elsewhere on the board
/ADC_AD777x/AIN1-: J1.23; also elsewhere on the board
/ADC_AD777x/AIN2+: J1.19; also elsewhere on the board
/ADC_AD777x/AIN2-: J1.20; also elsewhere on the board
/ADC_AD777x/TH1+: J1.28; also elsewhere on the board
/ADC_AD777x/TH1-: J1.29; also elsewhere on the board
/DEVICE_DETECT_1: J1.17, R3.1; also elsewhere on the board
/RESET_1: J1.11, R1.1; also elsewhere on the board
/SCL_1: J1.13; also elsewhere on the board
/SDA_1: J1.14; also elsewhere on the board
/SET_1: J1.10, R2.1; also elsewhere on the board
GND: J1.1, J1.12, J1.15, J1.16, J1.18, J1.21, J1.24, J1.27, J1.30, J1.P1, J1.P2, R1.2, R2.2; also elsewhere on the board

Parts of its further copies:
H5, H6, H7, H8: MountingHole; MountingHole_4.3mm_M4
J2: 550910374; CON_550910374_MOL
R4, R5: 100k; R_0603_1608Metric; LCSC C25803
R6: 10k; R_0603_1608Metric; LCSC C25804

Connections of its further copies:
+1V65: J2.2; also elsewhere on the board
+3V3: J2.9, R6.2; also elsewhere on the board
+3V3A: J2.8; also elsewhere on the board
+5VA: J2.4; also elsewhere on the board
+9VA: J2.6; also elsewhere on the board
+9Vb: J2.7; also elsewhere on the board
+18V: J2.3; also elsewhere on the board
-5VA: J2.5; also elsewhere on the board
/ADC_AD777x/AIN4+: J2.25; also elsewhere on the board
/ADC_AD777x/AIN4-: J2.26; also elsewhere on the board
/ADC_AD777x/AIN5+: J2.22; also elsewhere on the board
/ADC_AD777x/AIN5-: J2.23; also elsewhere on the board
/ADC_AD777x/AIN6+: J2.19; also elsewhere on the board
/ADC_AD777x/AIN6-: J2.20; also elsewhere on the board
/ADC_AD777x/TH2+: J2.28; also elsewhere on the board
/ADC_AD777x/TH2-: J2.29; also elsewhere on the board
/DEVICE_DETECT_2: J2.17, R6.1; also elsewhere on the board
/RESET_2: J2.11, R4.1; also elsewhere on the board
/SCL_2: J2.13; also elsewhere on the board
/SDA_2: J2.14; also elsewhere on the board
/SET_2: J2.10, R5.1; also elsewhere on the board
GND: J2.1, J2.12, J2.15, J2.16, J2.18, J2.21, J2.24, J2.27, J2.30, J2.P1, J2.P2, R4.2, R5.2; also elsewhere on the board

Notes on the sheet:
Mainboard: 550910274 / 55091-0274 -> 550910374 / 55091-0374 Add-on boards: 528850274 / 52885-0274 -> 528850374 / 52885-0374


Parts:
C32, C33, C35, C37, C38, C40, C42, C45: 100n; C_0603_1608Metric; LCSC C14663
C34, C36: 1u; C_0805_2012Metric; LCSC C28323
C39, C41: 4u7; C_1206_3216Metric; LCSC C29823
C43, C44: 20p; C_0402_1005Metric; LCSC C1554
C46: 10u; C_0805_2012Metric; LCSC C15850
D11: LED; LED_0805_2012Metric; LCSC C2296
J14: Micro_SD_CARD; CONN_503398-1892_MOL; LCSC C428492
R45: 68k; R_0603_1608Metric; LCSC C23231
R46, R61: 100k; R_0603_1608Metric; LCSC C25803
R47, R48, R51, R54, R55, R56, R57, R58, R59, R60: 10k; R_0603_1608Metric; LCSC C25804
R49: 12k; R_0603_1608Metric; LCSC C22790
R50: 1k; R_0603_1608Metric; LCSC C21190
R52, R53: 510k; R_0603_1608Metric; LCSC C23192
U6: USB2641-HZH-02; QFN-48-1EP_7x7mm_P0.5mm_EP5.3x5.3mm; LCSC C633596
U7: TS3A27518EPWR; TSSOP-24_4.4x7.8mm_P0.65mm; LCSC C443721
X1: X322524MOB4SI; Crystal_SMD_3225-4Pin_3.2x2.5mm; LCSC C70590

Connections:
+3V3: C32.1, C33.1, C35.1, C37.1, C38.1, C39.1, C40.1, C41.1, C42.1, C45.1, C46.1, J14.4 (VDD), R47.1, R54.1, R55.1, R56.1, R57.1, R58.1, R59.1, R61.1, U6.5 (VDD33), U6.12 (VDD33), U6.16 (VDD33), U6.25 (VDD33), U6.34 (VDD33), U6.41 (VDD33), U6.48 (VDD33), U7.8 (VCC); also elsewhere on the board
/DATA_SAVING/+5VBUS: R45.1; also elsewhere on the board
/DATA_SAVING/CRFLIT: C36.1, U6.15 (CRFILT)
/DATA_SAVING/D+: U6.42 (USB+); also elsewhere on the board
/DATA_SAVING/D-: U6.43 (USB-); also elsewhere on the board
/DATA_SAVING/EN_SD_MUX: R61.2, U7.20 (~EN); also elsewhere on the board
/DATA_SAVING/E_CLK: R56.2, U7.23 (NC3); also elsewhere on the board
/DATA_SAVING/E_CMD: R57.2, U7.21 (NC4); also elsewhere on the board
/DATA_SAVING/E_D0: R55.2, U7.1 (NC2); also elsewhere on the board
/DATA_SAVING/E_D1: R54.2, U7.2 (NC1); also elsewhere on the board
/DATA_SAVING/E_D2: R59.2, U7.22 (NC6); also elsewhere on the board
/DATA_SAVING/E_D3: R58.2, U7.19 (NC5); also elsewhere on the board
/DATA_SAVING/LED_IN: D11.2 (A), R50.2
/DATA_SAVING/LED_OUT: R50.1, U6.37 (LED)
/DATA_SAVING/MCLK: J14.5 (CLK), U7.7 (COM3)
/DATA_SAVING/MCMD: J14.3 (CMD), U7.9 (COM4)
/DATA_SAVING/MD0: J14.7 (DAT0), U7.6 (COM2)
/DATA_SAVING/MD1: J14.8 (DAT1), U7.4 (COM1)
/DATA_SAVING/MD2: J14.1 (DAT2), U7.12 (COM6)
/DATA_SAVING/MD3: J14.2 (DAT3), U7.10 (COM5)
/DATA_SAVING/PLL_FLIT: C34.1, U6.46 (PLLFILT)
/DATA_SAVING/RBIAS: R49.1, U6.47 (RBIAS)
/DATA_SAVING/SD_DET: J14.9 (DET)
/DATA_SAVING/SD_MUX_SEL: R60.1, U7.14 (IN2), U7.24 (IN1); also elsewhere on the board
/DATA_SAVING/SD_WP: R48.1, U6.13 (SD_WP)
/DATA_SAVING/SD_nCD: R51.1, U6.14 (SD_nCD)
/DATA_SAVING/USB2641_XTAL1: C44.1, R53.2, U6.45 (XTAL1), X1.1
/DATA_SAVING/USB2641_XTAL2: C43.1, R52.1, U6.44 (XTAL2), X1.3
/DATA_SAVING/USB2641_nRESET: R47.2, U6.38 (nRESET); also elsewhere on the board
/DATA_SAVING/USB_XTAL_R: R52.2, R53.1
/DATA_SAVING/U_CLK: U6.21 (SD_CLK), U7.15 (NO3)
/DATA_SAVING/U_CMD: U6.24 (SD_CMD), U7.17 (NO4)
/DATA_SAVING/U_D0: U6.18 (SD_D0), U7.13 (NO2)
/DATA_SAVING/U_D1: U6.17 (SD_D1), U7.11 (NO1)
/DATA_SAVING/U_D2: U6.33 (SD_D2), U7.16 (NO6)
/DATA_SAVING/U_D3: U6.32 (SD_D3), U7.18 (NO5)
/DATA_SAVING/VBUS_DET_3V: R45.2, R46.1, U6.39 (VBUS_DET)
GND: C32.2, C33.2, C34.2, C35.2, C36.2, C37.2, C38.2, C39.2, C40.2, C41.2, C42.2, C43.2, C44.2, C45.2, C46.2, D11.1 (K), J14.6 (VSS), J14.10 (SHIELD), J14.11 (VSS), J14.12 (VSS), J14.13 (VSS), J14.14 (VSS), R46.2, R48.2, R49.2, R51.2, R60.2, U6.40 (TEST), U6.49 (GND), U7.5 (GND), X1.2, X1.4; also elsewhere on the board

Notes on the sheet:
SD CARD
SD Card MUX
Memory to save all the data
Write with ESP32 / Read with GL3224


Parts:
C30, C31: 100n; C_0603_1608Metric; LCSC C14663
U5: LSM6DSVETR; LGA-14_3x2.5mm_P0.5mm_LayoutBorder3x4y; LCSC C41785564

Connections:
+3V3: C30.2, C31.2, U5.5 (VDD_IO), U5.8 (VDD); also elsewhere on the board
/IMU/CS_LSM: U5.12 (CS); also elsewhere on the board
/IMU/MISO: U5.1 (SDO); also elsewhere on the board
/IMU/MOSI: U5.14 (SDA); also elsewhere on the board
/IMU/SCLK: U5.13 (SCL); also elsewhere on the board
GND: C30.1, C31.1, U5.2 (SDx), U5.3 (SCx), U5.6 (GND), U5.7 (GND); also elsewhere on the board

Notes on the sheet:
Inertial Measurement Unit (IMU)
To know the orientation of the device



Board: 4 copper layers, 208.0 x 129.0 mm, 287 parts (7 on the bottom side), 192 nets.

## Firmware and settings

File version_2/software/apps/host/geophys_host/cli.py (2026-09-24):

"""Command-line entry point for V2 host/device integration."""

from __future__ import annotations

import argparse
import asyncio
from contextlib import ExitStack
from pathlib import Path
import sys
import time

from .capture import RawRecordCapture
from .ble_client import BleHelloClient, discover_ble_devices
from .live import LiveStreamModel, MatplotlibLiveView
from .protocol import (
    REPLY_DEVICE_CONFIG,
    REPLY_DEVICE_INFO,
    REPLY_STREAMING_START_RESULT,
    REPLY_STREAMING_STOP_RESULT,
    RESULT_SUCCESS,
    ProtocolError,
    VALID_STREAM_DECIMATIONS,
    decode_device_config,
    decode_device_info,
    decode_streaming_start_result,
    decode_streaming_stop_result,
    encode_device_get_config,
    encode_hello,
    encode_streaming_start,
    encode_streaming_stop,
)
from .serial_client import SerialClient, request_device_info
from .stream_parser import AdcRecordMessage

CHANNEL_MASK_ARGUMENTS = {
    "0-3": 0x0F,
    "4-7": 0xF0,
    "all": 0xFF,
}


def _print_device_info(info) -> None:
    print(f"result={info.result}")
    print("mac=" + ":".join(f"{byte:02x}" for byte in info.mac_address))
    print(f"hardware_version={info.hardware_version}")
    print(f"hardware_revision={info.hardware_revision}")
    print(f"firmware_version={info.firmware_version}")


async def _run_ble_hello(identifier: str, timeout_s: float) -> int:
    client = BleHelloClient(identifier)
    await client.connect()
    try:
        info = await client.hello(timeout_s)
    finally:
        await client.disconnect()
    _print_device_info(info)
    return 0


def _require_success(label: str, result: int) -> None:
    if result != RESULT_SUCCESS:
        raise RuntimeError(f"{label} failed with result 0x{result:02x}")


def _format_status(model: LiveStreamModel, invalid_records: int,
                   bytes_discarded: int) -> str:
    snapshot = model.snapshot()
    statuses = ",".join(
        f"{status}:{count}"
        for status, count in sorted(snapshot.status_counts.items())
    ) or "none"
    return (
        f"blocks={snapshot.blocks_received} "
        f"conversions={snapshot.conversions_received} "
        f"rate={snapshot.conversion_rate_hz:.1f}/s "
        f"missing={snapshot.missing_conversions} "
        f"payload_gaps={snapshot.payload_discontinuities} "
        f"bad_blocks={invalid_records} "
        f"discarded_bytes={bytes_discarded} "
        f"status={statuses}"
    )


def _run_live(arguments: argparse.Namespace) -> int:
    viewer = None
    stream_started = False
    terminal_line_active = False

    with ExitStack() as stack:
        capture = None
        client = stack.enter_context(SerialClient(
            arguments.port,
            arguments.baud,
            write_timeout_s=arguments.timeout,
        ))

        info = decode_device_info(client.request(
            encode_hello(), REPLY_DEVICE_INFO,
            timeout_s=arguments.timeout))
        _require_success("HELLO", info.result)
        config = decode_device_config(client.request(
            encode_device_get_config(), REPLY_DEVICE_CONFIG,
            timeout_s=arguments.timeout))
        _require_success("DEVICE_GET_CONFIG", config.result)

        requested_mask = (
            config.adc_channel_mask
            if arguments.channels is None
            else CHANNEL_MASK_ARGUMENTS[arguments.channels]
        )
        if requested_mask == 0:
            raise RuntimeError(
                "the device configuration has no active ADC channels; "
                "pass --channels or configure the device first")

        start = decode_streaming_start_result(client.request(
            encode_streaming_start(arguments.decimation, requested_mask),
            REPLY_STREAMING_START_RESULT,
            timeout_s=arguments.timeout,
        ))
        _require_success("STREAMING_START", start.result)
        if start.channel_mask == 0:
            raise RuntimeError("device accepted a stream with no channels")
        stream_started = True
        model = LiveStreamModel(
            window_s=arguments.window,
            source_sequence_step=start.decimation or 1,
        )

        def handle_record(message: AdcRecordMessage) -> None:
            model.append(message.record)
            if capture is not None:
                capture.append(message.raw)

        try:
            if arguments.capture is not None:
                capture = stack.enter_context(
                    RawRecordCapture(arguments.capture))
            if not arguments.terminal:
                viewer = MatplotlibLiveView(
                    start.channel_mask, arguments.window)

            print(
                f"stream started: channels=0x{start.channel_mask:02x} "
                f"decimation={start.decimation or 1} "
                f"recording={'yes' if start.recording_in_progress else 'no'}",
                file=sys.stderr,
            )
            started_at = time.monotonic()
            keepalive_at = started_at + 1.0
            draw_at = started_at
            try:
                while True:
                    now = time.monotonic()
                    if arguments.duration is not None and \
                            now - started_at >= arguments.duration:
                        break
                    if viewer is not None and not viewer.is_open:
                        break

                    message = client.read_message()
                    if isinstance(message, AdcRecordMessage):
                        handle_record(message)

                    now = time.monotonic()
                    if now >= keepalive_at:
                        live_config = decode_device_config(client.request(
                            encode_device_get_config(),
                            REPLY_DEVICE_CONFIG,
                            timeout_s=arguments.timeout,
                            on_record=handle_record,
                        ))
                        _require_success(
                            "DEVICE_GET_CONFIG", live_config.result)
                        keepalive_at = time.monotonic() + 1.0

                    if now >= draw_at:
                        if viewer is not None:
                            viewer.update(
                                model,
                                client.parser.invalid_records,
                                client.parser.bytes_discarded,
                            )
                        else:
                            print(
                                "\r" + _format_status(
                                    model,
                                    client.parser.invalid_records,
                                    client.parser.bytes_discarded,
                                ),
                                end="",
                                flush=True,
                            )
                            terminal_line_active = True
                        draw_at = now + arguments.refresh
            except KeyboardInterrupt:
                pass
        finally:
            try:
                if stream_started:
                    stop = decode_streaming_stop_result(client.request(
                        encode_streaming_stop(),
                        REPLY_STREAMING_STOP_RESULT,
                        timeout_s=arguments.timeout,
                        on_record=handle_record,
                    ))
                    _require_success("STREAMING_STOP", stop.result)
                    stream_started = False
            finally:
                if capture is not None:
                    capture.flush()
                if viewer is not None:
                    viewer.close()

        if terminal_line_active:
            print()
        print(_format_status(
            model,
            client.parser.invalid_records,
            client.parser.bytes_discarded,
        ))
        if capture is not None:
            print(
                f"capture={capture.path} "
                f"blocks={capture.blocks_written} "
                f"bytes={capture.bytes_written}"
            )
    return 0


def _positive_float(value: str) -> float:
    parsed = float(value)
    if parsed <= 0.0:
        raise argparse.ArgumentTypeError("must be positive")
    return parsed


def main() -> int:
    parser = argparse.ArgumentParser(prog="geophys-host")
    subparsers = parser.add_subparsers(dest="command", required=True)

    hello = subparsers.add_parser("hello", help="request DEVICE_INFO")
    hello.add_argument("port")
    hello.add_argument("--baud", type=int, default=921_600)
    hello.add_argument("--timeout", type=_positive_float, default=2.0)

    ble_scan = subparsers.add_parser(
        "ble-scan", help="scan for the device's BLE advertisement")
    ble_scan.add_argument("--timeout", type=_positive_float, default=3.0)

    ble_hello = subparsers.add_parser(
        "ble-hello", help="connect over BLE and request DEVICE_INFO")
    ble_hello.add_argument("device", help="BLE address or macOS identifier")
    ble_hello.add_argument("--timeout", type=_positive_float, default=3.0)

    live = subparsers.add_parser(
        "live", help="plot or print the live ADC stream")
    live.add_argument("port")
    live.add_argument("--baud", type=int, default=921_600)
    live.add_argument("--timeout", type=_positive_float, default=2.0)
    live.add_argument(
        "--channels", choices=tuple(CHANNEL_MASK_ARGUMENTS),
        help="requested channels (default: current device mask)")
    live.add_argument(
        "--decimation", type=int, choices=VALID_STREAM_DECIMATIONS,
        default=0,
        help="stream decimation; 0 means no decimation")
    live.add_argument(
        "--window", type=_positive_float, default=5.0,
        help="visible plot window in seconds")
    live.add_argument(
        "--refresh", type=_positive_float, default=0.1,
        help="display refresh interval in seconds")
    live.add_argument(
        "--duration", type=_positive_float,
        help="stop automatically after this many seconds")
    live.add_argument(
        "--capture", type=Path,
        help="write validated 512-byte DAT blocks to a new file")
    live.add_argument(
        "--terminal", action="store_true",
        help="show counters in the terminal instead of opening a plot")

    arguments = parser.parse_args()
    if arguments.command == "hello":
        info = request_device_info(
            arguments.port, arguments.baud, arguments.timeout)
        _print_device_info(info)
        return 0
    if arguments.command == "ble-scan":
        devices = asyncio.run(discover_ble_devices(arguments.timeout))
        for device in devices:
            print(f"{device.identifier}\t{device.name}")
        return 0
    if arguments.command == "ble-hello":
        return asyncio.run(_run_ble_hello(
            arguments.device, arguments.timeout))
    if arguments.command == "live":
        return _run_live(arguments)
    return 2


def entrypoint() -> int:
    try:
        return main()
    except (OSError, ProtocolError, RuntimeError, TimeoutError) as error:
        print(f"geophys-host: {error}", file=sys.stderr)
        return 1


if __name__ == "__main__":
    raise SystemExit(entrypoint())

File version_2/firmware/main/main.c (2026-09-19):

#include <stddef.h>

#include "adc_scope_test.h"
#include "app.h"
#include "board.h"
#include "freertos/FreeRTOS.h"
#include "freertos/task.h"
#include "platform_time.h"

static void stop_in_safe_state(void)
{
    (void)board_enter_safe_state(NULL);
    for (;;) {
        vTaskDelay(portMAX_DELAY);
    }
}

void app_main(void)
{
    fw_error_context_t error;
    if (platform_monotonic_time_initialize(&error) != FW_STATUS_OK) {
        stop_in_safe_state();
    }

    if (board_init(&error) != FW_STATUS_OK) {
        stop_in_safe_state();
    }

#if CONFIG_GEOPHYS_ADC_SCOPE_TEST
    if (adc_scope_test_start(&error) != FW_STATUS_OK) {
        stop_in_safe_state();
    }
    for (;;) {
        vTaskDelay(portMAX_DELAY);
    }
#else
    if (app_start(&error) != FW_STATUS_OK) {
        stop_in_safe_state();
    }
#endif
}

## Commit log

2026-08-19 Initial project scaffold
    [ADC.kicad_sch, GNSS.kicad_sch, GPS_tile.kicad_sch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]
2026-08-25 Small uncertain KiCad update to the files
    [ADC.kicad_sch, GNSS.kicad_sch, connectors_io.kicad_sch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]
2026-08-25 IA update to V2 board rev1 contract.md
2026-08-25 IA update to V2 board rev1 product_requirements.md
2026-08-25 IA update to V2 board rev1 firmware_interfaces.md
2026-08-25 Making sure the MUX SD is connecting the SD Card to the ESP32 and the USB2641 is help in reset
2026-08-27 Adding platform SPI commands with or without the DMA
2026-08-27 Adding UART communication test coming next
2026-08-27 Adding error reporting (FW-11)
    [platform_gpio.c, platform_spi.c, platform_spi.h]
2026-09-02 Add task-context microsecond delay to ESP32-S3 platform
2026-09-02 Implement Rev-1 board mapping and safe-state control
2026-09-02 Add temporary rail-sequencing oscilloscope diagnostic
2026-09-02 Adding AD7779 driver part FW-20
2026-09-02 Adding AD7779 driver part FW-21
2026-09-10 Adding the analog card detect driver
2026-09-17 Add ESP32 ROM CRC wrappers
2026-09-17 Add ADC record scaffold
2026-09-17 feat(firmware): add 10 MHz monotonic timer
2026-09-17 feat(protocol): implement HELLO device handshake
2026-09-17 adding hello and config commands. recordings commands left to implement
    [device_config_reply.txt, device_get_config_request.txt, device_set_config_request.txt]
2026-09-24 docs: update protocol and implementation status
    [ANALOG_BALANCING.kicad_sch, Bridge_offset.kicad_sch, CONN.kicad_sch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]
2026-09-28 feat(data): add shared ADC recording decoder
2026-09-29 feat(firmware): stabilize ADC power-up and SPI timing
2026-09-29 fix(firmware): keep DRDY disabled during ADC startup
    [platform_gpio.c]
2026-09-29 docs: record ADC startup and high-rate validation
2026-09-30 perf(firmware): streamline ADC acquisition hot path
2026-10-01 Optimize AD7779 acquisition and frame SPI bursts
2026-10-02 Add magnetic controls and PSRAM storage buffering
2026-10-13 Document Helmholtz coil calibration plan
2026-10-13 Set permanent coil ballast for 18 AWG winding
2026-10-13 Record measured Helmholtz coil resistance
2026-10-13 Record Alpha Wire winding specifications
2026-10-13 Persist ADC settings and add recording headers with batched SD writes
2026-10-23 Add magnetic board simulation models and improve recording tools
    Add tested SPICE models and a Helmholtz simulation workbook, with updated lab notes. Rename the shared Python decoder package to geophys-recording and extend the recording viewer with nominal thermis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
2026-10-27 Checkpoint working firmware with automatic acquisition on battery power
    User confirmed that the device starts acquisition automatically when powered on by a battery. Preserve this working firmware baseline before adding W2 synchronization pulse recording.
